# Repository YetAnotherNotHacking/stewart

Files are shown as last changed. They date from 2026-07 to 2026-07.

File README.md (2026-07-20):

<p align="center">
  Project Banner
</p>

<h1 align="center">Stewart Platform Controller</h1>

<p align="center">
  ESP32 • PCA9685 • 6 DoF
</p>

<p align="center">
  A simple, open implementation of a Stewart's platform with kinematics for all 6 DoF.
</p>

# About
This is a simple implementation of a Stewart's platform, something commonly used in settings like simulators or other applications of high strength high dof platforms. This uses an ESP32 and PCA9685 Servo Controller driving MG996r servos to allow for high quality control of the platform.

This reposity also includes a robust desktop control app, currently featuring jog movement and jump to position control for the platform using the ESP's wireless networking. It's planned for later integration for heavier automation (possibly Lua based) to make it easier to automate the platform.

## Resources:
Things to help you around this project

### Assembly
An assembly guide for how to build the project is here: [link](https://docs.google.com/presentation/d/1fX6R6pKFSlhVpZevY7VcBayyEp1o772PA0JAKRDqIYo/edit?usp=sharing)

### Wiring
An image showing the wiring nessecary for the project is below.:
stewartwiring

### Programming
See the `code/` folder of this repo!

The desktop code can be run be downloading all of the python files and running main.py. You may need to create an `__init__.py`. Once I have the hardware and confirm it's functionality, I will ship the app more properly as a cross compliled bundled application. For now, however, you are going to need to download and run all scripts.

The ESP32's code can be flashed like any other code. See more information at the end of the assembly guide.

### Bill of Materials:
You can see the bill of materials [here]([url](https://docs.google.com/spreadsheets/d/1tSShUhzgmsK12tPjXI03KWSomIxZK9p5Zw8UYwgLAco/edit?usp=sharing)). I am purchasing a 12v supply to fix another project, the buck is cheaper than a dedicated high amperage 5v supply. You can achieve the same thing with a 5v supply, with atleast 6 amps. The HackClub grant will not be used to pay for the power supply. This also assumes you have assorted m3 screws lying around, if you do not, add another 9.99 for [these]([url](https://www.amazon.com/Fgruh-750PCS-Assortment-Washers-Assorted/dp/B0FGV5FCBN)) on Amazon.

| Component | Qty | Unit Price | Total | Link |
|---|----:|---:|---:|---|
| Buck Converter (24V/12V → 5V) | 1 | $9.99 | $9.99 | https://www.amazon.com/HOMELYLIFE-Efficiency-Protection-Automotive-Surveillance/dp/B01M03288J |
| ESP32 | 1 | $9.99 | $9.99 | https://www.amazon.com/Development-integrates-Bluetooth-Connection-Programming/dp/B0FGHX4JZ7?s=electronics |
| Servo Controller (PCA9685) | 1 | $8.99 | $8.99 | https://www.amazon.com/EC-Buying-16-Channel-Interface-Expansion/dp/B0GD7BMXHH?s=electronics |
| Pushrods | 1 | $9.98 | $9.98 | https://www.amazon.com/Adjustable-Pushrod-Connector-Airplane-Aircraft/dp/B086C4Q5RS |
| MG996R Servos (6-Pack) | 1 | $21.39 | $21.39 | https://www.amazon.com/KEAcvise-Packs-mg996r-servo-Motor/dp/B0FGP9ZPJN |
| 12V Power Supply | 1 | $14.87 | $14.87 | https://www.ebay.com/itm/177618885952?var=477234645275 |
| **Total** | **6** |  | **$95.21** | |

### Adaptation:
Currently, this platform is more of a kinematics demo then something that solves any real problem. The step files and fusion export for the main assembly are included in the `cad/` folder to allow you to modify this for whatever needs you have. Feel free to use this, its open source and I put no requirements on it.

### Support:
If you ever need any support, feel free to create an issue on this repository and I will try to get back to you as fast as I can!

## Render:
0b346e73-0dd3-4ae0-838e-4d3ce46c3656

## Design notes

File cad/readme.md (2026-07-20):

# Cad
This is all of the cad for the project.
Main fusion export, and stl/step exports of all files are here.

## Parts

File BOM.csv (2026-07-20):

item | count | cost per | cost total | link
Buck Converter (24/12v to 5v) | 1 | 9.99 | 9.99 | https://www.amazon.com/HOMELYLIFE-Efficiency-Protection-Automotive-Surveillance/dp/B01M03288J
ESP32 | 1 | 9.99 | 9.99 | https://www.amazon.com/Development-integrates-Bluetooth-Connection-Programming/dp/B0FGHX4JZ7?s=electronics
Servo Controller | 1 | 8.99 | 8.99 | https://www.amazon.com/EC-Buying-16-Channel-Interface-Expansion/dp/B0GD7BMXHH?s=electronics
Pushrods | 1 | 9.98 | 9.98 | https://www.amazon.com/Adjustable-Pushrod-Connector-Airplane-Aircraft/dp/B086C4Q5RS
Servos MG996r | 1 | 21.39 | 21.39 | https://www.amazon.com/KEAcvise-Packs-mg996r-servo-Motor/dp/B0FGP9ZPJN
12 Volt power supply | 1 | 14.87 | 14.87 | https://www.ebay.com/itm/177618885952?var=477234645275

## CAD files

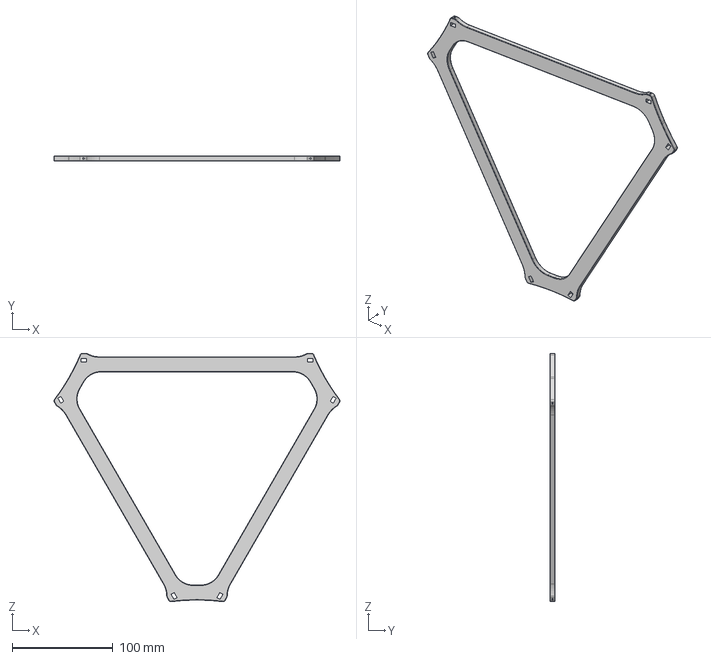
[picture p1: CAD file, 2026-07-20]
cad/plate.step
284.1 x 5.00 x 246.7 mm

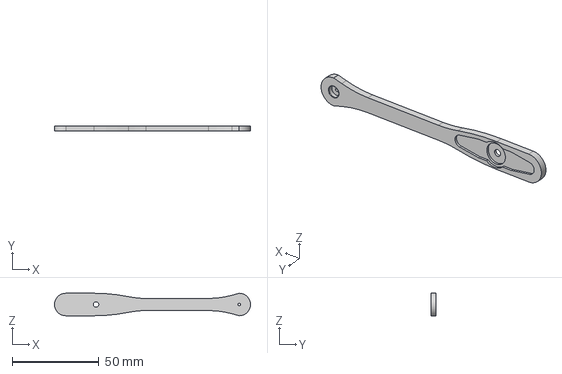
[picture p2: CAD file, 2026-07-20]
cad/control-arm.step
113.0 x 3.00 x 13.0 mm

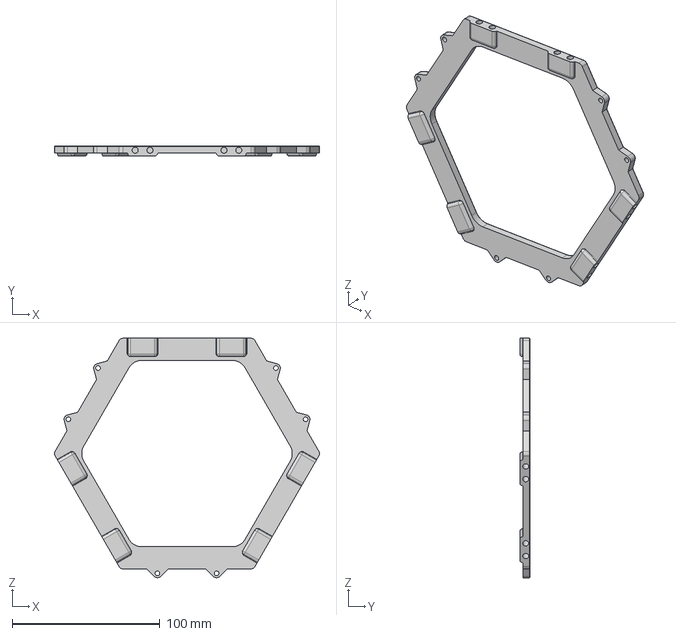
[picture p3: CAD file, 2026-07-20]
cad/top_plate.step
179.1 x 7.00 x 161.9 mm

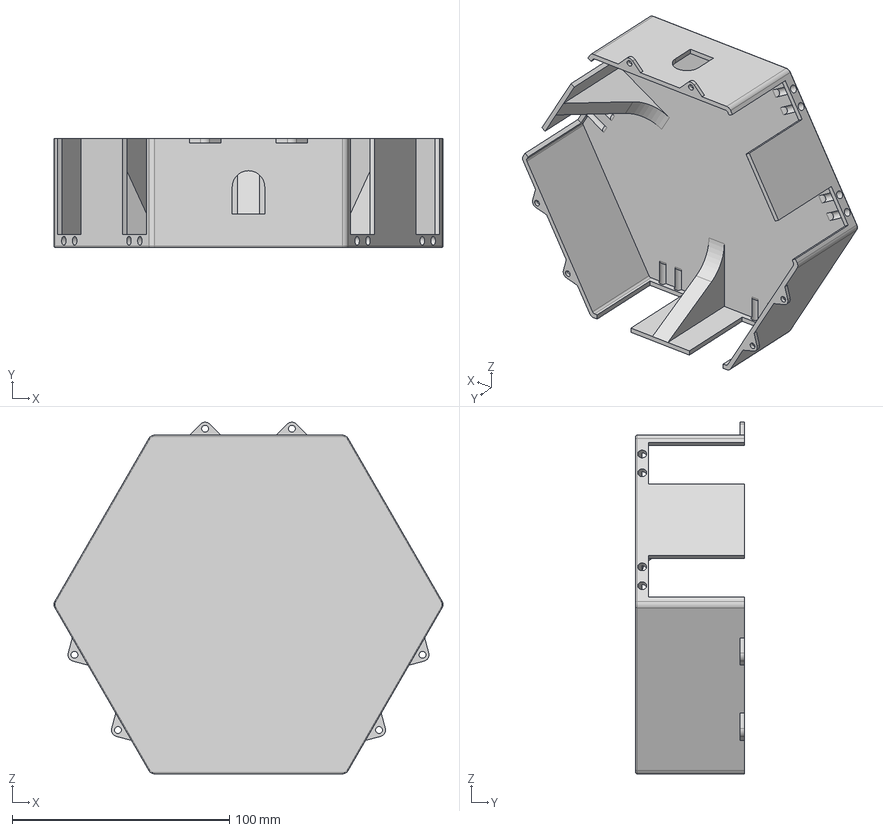
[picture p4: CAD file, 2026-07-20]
cad/base.step
179.1 x 50.0 x 161.9 mm

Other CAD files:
cad/base.stl
cad/control-arm.stl
cad/plate.stl
cad/top_plate.stl

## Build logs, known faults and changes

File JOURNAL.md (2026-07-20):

# July 4: Basic concept understanding, and working on the cad.
I have seen several other implementations of Stewart's platforms, however, all of them seemed to not nesecarily be super robust or able to take any decent payload. I want to make something that is able to have a generic payload adapter (similar to my previous gimbal project). I will look at another design for a base and try to work out how I can best increase the robustness and usability.

{7708621C-4849-4F1F-8B9E-15CF98B89B5D}

Above is the image that I am taking inspiration from. The design that they implemented is very simple, but you are able to see how everything works so I am going to use it as a base for my project.

I also had the recommendation from a friend to use mg996r servos for anything where any amount of load is being moved. I also concidered other servos, but looking around, the price to performance of the servos that he recommended are just best. They are also semi-frequently sold in packs of 6

Servo sourcing plan (cheap, good reviews, and 6 pack)

https://www.amazon.com/KEAcvise-Packs-mg996r-servo-Motor/dp/B0FGP9ZPJN

I am now going to figure out how closely I can logically package the servos into the base. The goal is a more compact base for easy adaptation in the future.

{B584B507-7369-4E37-B5E9-1328EBD415F6}

Above is what I came up with. It should be noted that the servos are sticking out, this is worst case clearance here to ensure they will fit well. There is also a plan to later integrate a 9 dof imu into the top of the case for later control improvements. (space is being left in the container so they will fit internally, to make later modification easier)

{6741CD3E-74F1-46A1-B29D-13A477A4EEA9}

This is what it looks like stood up. I notice that the 3 little walls (which will be bearing a decent amount of load) are really thin, and it is making me nervous, so I will ensure there are more layers for that to be a little more rigid in the future.

{BA7941BE-7033-4282-A654-466BBA05E55F}

I added the bottom screw holes (above). They look a bit weird, but I believe that this will be sufficient. If not, I have a rediculous amount of petg and can just reprint the part until its good enough. The plan will be to have the second (top) screw couples on the top element/top case. This is mainly to be easier to print without fail. I need to first make a way for the top of this to attach however.

{ADCCC9FD-2649-416B-894D-74BAC281DD39}

I added mounting holes for the top onto the walls that have less load on them to ballance it out. I also added a passthrough with some slight printing optimizations to the side to allow the power and possibly a control cable to be run through the side of the model.

{3E43B1B1-DBBC-4251-BCD3-43D21B207348}

Like I said, I was nervous about the thickness of these little walls so I have added these wedge things in order to improve the rigidity. I will have to account for them in the design of the top of this, as they are going right up to the edge of the wall. Anyway, I will now put everything together in the main assembly how it is to see how the packaging is looking.

{264E91C8-03C2-4743-A8B0-B292043C7E27}

I think it looks decent, I will continue with designing the top. I also see that with how I want to mount the servos, that they are going to require free space at the top of the model for their cables, this is unfortunate. I should also note that I am planning to use the left over m3 screws that I have from the Potatomatic project to assemble this in order to save costs.

{C7A08C58-994B-41CB-BDE0-317925B3F584}

Here is a rough concept of the top plate.

{55CF6593-B2A6-4264-8C56-0BE5EBFA97F7}

And here it is in the main assembly.

{2EB23810-CFFF-498B-9FF3-BDC86DFFC4B5}

Looking at where the servo attaches, it seems it will be nessecary for me to drop down the plate a little more for it to be thick enough on the bottom. I will also need to raise it roughly a millimeter on the top for more material there as well. It sucks that there is no way to print this that makes it so that the screw isnt going to be splitting the layers apart.

{193AC73F-C306-4EBB-A3E5-E983F9CDB948}

I have now polished the part.

{ACE63CB6-6EF3-4794-8CF9-CCE3B20B8174}

The screw holes for the servos are now properly in place and have sufficient thickness in the places where it's needed.

{DC22E7E0-B3A2-44E5-8347-32755850A53D}

This is the overall look now. I will next move onto the part of designing the control arms, but I first want to do a little bit of research to figure out how the length/other factors changes the behaviour.

https://raw.org/research/inverse-kinematics-of-a-stewart-platform/

I found this awesome website, with a super awesome article detailing the inverse kinematics, not only this, it allowed me to easily tweak the settings of the control arms and driving rod lengths. This gave valuable insight, as I now understand how the length effects it. I spent about 10 minutes looking a little bit into their code (which I understood none of :sob:) as well as playing with the length of the control arms.  From looking at it. the only effect that they really have is the range of motion that your platform has. For example, short control arms means you are only able to move your platform a little bit, but the lack of precision of the servos is accounted for a little bit better, and with longer ones, any error of the servos is amplified but you get decently larger range of motion. I also noticed if they are too long, they are able to collide with eachother. So next, I am going to find step files for the servo horns, and model a control arm that maximizes the achievable positions of the system.

{CC1C07BD-DBCB-4EA6-AB8A-6E77BAE61B1C}

Hmmmmm... those are going to collide at this size....
Luckily I made everything intent driven, so it will simply be changing a few numbers to change everything. Still sucks though.

{1E59FDD9-F150-4E86-BC50-04DC1E2669FB}

Fusion is testing my pacience. It broke the entire model for the base, I spent a bit fixing that. Some of the geometry sketches for the mounting holes were constrained wrongly when they were copied between the sketches, and a lot of them just decided they want to fail to compute. Then, after fixing all of the base, I tried updating the model just to see the damage, and was greeted with this wonderful piece of modern artwork (slop) that I will now have to spend my time fixing. Delightful!

{CC3863F8-A4AC-4C55-9D65-8D3235942493}

I will first fix this top plate, then reconstrain everything again. For me this feels less overwhelming then fixing a ton of small errors.

{464E0E61-C5F8-4216-B478-98CCD330A679}

Intent driven for the win :100: I love intent driven :heart:

The top was much easier to fix since I did everything properly. It was changing about 4 numbers between 2 sketches and everything was all good. I will now re insert and joint all of the servos together.

I also verified that the servos have the required range of motion, they seem to be 360 which is not standard for these servos to my understanding.

{35CF77CF-9B23-4C36-8AD6-604776D82AB0}

I now have all of the things put on there.

{0F38C60F-6E5E-4631-A7CB-6289051E86CA}

Here is the hole that the servo horn is going to get put on.

{7766989E-C96C-4622-A41C-EEDB0266B852}

I realized I forgot the way to screw it in, this is what I came up with. The m3 screw that is included will be too short, so I am going to replace it with one of my own, longer ones. I may also improve this geometry, but my printer is probably too crap for it to matter anyway.

{7359E234-FEF2-4035-8B6E-4F17F7F43342}

I made the arm a little thinner, it was really thick, and it will be in petg so I know the strength is not going to be an issue.

{42FDEA49-88B1-4488-A795-8FD30214A6F2}

I have continued to optimize this for the control rod attachment, I made sure that the fixtures will attach as best as possible. I am still a little unsure of how it will all end up factoring together, so I will try and make the push rods next just to see what they are going to look like roughly.

{0284CCE8-381B-44F2-9D7C-2662C3E2D7CF}

Man...... these pushrods are really thin aren't they.....
Im sure it wont be a problem

https://www.amazon.com/HobbyPark-Adjustable-Connector-Pushrods-Replacement/dp/B08CBSWMR5/141-2591928-2634929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

Above are the pushrods that I am intending to get btw. I also had to learn how to use the sweep tool to make them in fusion :sob:

{E34BBB38-DA87-4670-9158-C333024C7C63}

I may end up shortening the control rods in real life if they aren't rigid enough. They look like they will fail fast honestly. I also worry that once they are bent, that they aren't going to be easy to unbend and get working again.

Sorry for big dev log today. It is currently the next day actually, so this is technically multiple days of work.

I also made a bom, this was a few days ago when I was still planning the rough idea of the project out, but it is still unlogged work.

https://docs.google.com/document/d/1bmJ8n-eDoXSdFWSxfQN4pvn6DaG_fgnzeeZT4vmXuGE/edit?usp=sharing

** Total time spent: 5.9 hours **

# July 5: Working on the top payload, and kinematics/code
I speant the first 40 minutes today working on the top platform that the plate will be attached to. I still dont know for sure what I am going to do for the plate, it will have to be something transparent to make use cases like bouncing a ping pong ball easier.

{D2C29C5F-D418-43F5-B01C-BD269D2E2E26}

Above is the image of what that looks like in the overall design. I cant decide if I am going to bend the push rods like shown, or if I am going to take advantage of the link things that come in the kit of them. The kit isnt super clear about their size so I dont know how to cad for them without having that. I have a place to either bend the wire or put a bolt, depending on what I end up doing.

Youtube of cad, stopped trying lapse because it NEVER works. Sorry for 1x speed, and weird aspect ratio (peak framework).
https://www.youtube.com/watch?v=UD7uxmYwpVk

I will now look into how I can implement the kinematics engine into python.

For working on the kinematics, I need to first get some of the main parameters for the control, those are: horn length, rod length, base radius and base raduis outer, platform radius, platform radius outer, shaft distance, anchor distance. (disclosure: I am getting help from Gemini to understand the kinematics, as well as refferencing the stewart.js from the web demo I talked about yesterday. I don't understand a majority of the math so I am seeking LLM assistance, everything else I will be writing myself.)

Here are the values I have measured from my model (note: all in mm)

```python
horn_length = 82.50
rod_length = 169.00
base_radius = 97.342
base_radius_outer = 90.00
platform_radius = 81.293
platform_radius_outer = 123.198
shaft_distance = 30.00
anchor_distance = 112.50
```

Horn length: 

{3A344BA8-43A7-4DE4-A1C0-9EBD12153CDD}

Rod length:

{7ADF7757-6D76-44C3-9E2A-94BBC2EA63F2}

Base Radius:

{16644CE8-8193-4C16-9567-7A8AE65D8448}

{168CA614-B971-422A-B4B4-20F02DB826A6}

Base Radius (outer):

{52B913E2-7397-4D8C-B3CC-4CA2CCBF47E9}

Platform Radius:

{A6326FF2-A38A-445D-87B1-B7B76F02757F}

Platform Radius (outer):

{00A32B14-F5F0-42A4-81A5-427C9D99E484}

Shaft Distance:

{BF8E1D49-5830-47E3-A02E-939B34D53DE6}

Anchor Distance:

{696FCF2E-CB64-4703-B590-D0A17781D279}

Now that I have these measurements, I am going to boot back into Linux where my development environment is, and work on the rest of the programming. I want to make a TKinter control GUI, and basic easy to control kinematics. I plan to also look into how difficult a 3d preview of the movements would be. I also need to write the firmware for the esp32 that it will be controlling. The idea is to have the code run mainly on the laptop, and use the lan to connect to the esp32 and issue the servo angles. All kinematics will be done in the desktop companion app for simplicity.

I spent about 2 more hours working on the code for the project, this simple tkinter gui was super obnoxious to make. I just need to add jump to position, position validity verification, connection logic and piping the position to the kinematics so the commands can be sent and this project will largely be completed. Overall, I think that this is not the most complicated part of the gui and that a lot more time is going to need to be spent in order to complete this. Namely, the connection is something that is going to take a while. I most likely will want to do something websocket based running on the esp32, and some of light feedback in it for better control. I am not sure yet. I also want to add a 3d visualizer to the gui, similar to the one website that I found the stewart.js library from. Overall, with what was done today I know that there is still a lot more to come. In the end, this is a code heavy project rather than hardware heavy (hence me doing t3).



Note: yes, it's open in antigravity, but thats bc its the only ide I have configured with everything on this machine (other than FRC VSCode which is missing hackatime). The hackatime project is stewartcontroller, I tried to share it, but it says "anyone with the link can view it" but I litteraly cant find a public link anywhere. The only link I see has /my/ which I know won't work on another machine, if it did, so many duplicates would have to exist. I will assume it being public is enough for whoever is reviewing the project. Lmk if there is anything else that I need to do. I did also get some help with small syntax errors from ChatGPT and other missuses of tkinter, bc honestly this is my first time in a while not just fully vibe coding the interface, I have forgotten most of even the basic stuff unfortunately. I used to be good at this :sob:

** Total Time Spent: 3.5 hours **

# July 19: Finishing code, finalizing for ship
After finishing getting distracted by the FTC premier event and working on a new drivebase for next year, I finally have gone back to this project to get it finished and out of the way. I also need the 12v supply this project will fund over other things, so I am trying to get this shipped asap. I know Forge is against AI firmware, but I dont really know cpp so I had to get some help from gemini. I used it to assist with basic usage of the apis I needed to host a wireless network and parse json in order to control this project effectively.

I ended up finishing it up, and it looks something like this:



Litteraly just accepting a json object of the positions and sending the pwm signal to each of the servos in order to set their position.

I also had some assistance from gemini in order to create a visualization of the platform:



I have kept it so that the code is less than 30% written by ai, though of the 70% of my code about 50% of it was written with assistance (asking how to use apis in context, but implemnting myself) (all of this is just as a disclosure)

I will now boot back into windows and begin work on assembly, wiring, and other finalization to meet the requirements. I will also copy the code from the other repository that I made accidentally to here.

{FB7F5493-3F80-4C67-B9E0-88EF0DA67D7C}

I have made the bom.csv (above). it should be noted that the 12v and buck are nessecary rather than just a 5v, as the power supply is needed to save another Forge project I can't complete since the power supply unfortunately was fried. (This is to fix Potatomatic)

I have also exported all of the cad in the requested format as well as stl for easier printing of the project. Its all in the `cad/` folder of the repo. I will next complete the assembly guides and wiring diagrams.

Here is the finished assmebly guide and wiring diagram combo:

https://docs.google.com/presentation/d/1fX6R6pKFSlhVpZevY7VcBayyEp1o772PA0JAKRDqIYo/edit?usp=sharing

Finally, I made an image in sketchpad for the repo banner and forge banner.

{38EFED0E-58FD-4C1D-82DD-88AE67AA784D}

I then put together the readme file, finalized everything to meet the forge shipping requirements, all of this took a little over 30 minutes however I was waiting for a render for part of that time that I will not count. I ended up scrapping that render and using the one from the assembly guide anyway.

{5F63E4D0-7F8A-474A-ABB6-F0F511B82756}

I will now update this journal one final time and submit the project for review!

Hackatime: 


** Total time spent: 2.6 hours **

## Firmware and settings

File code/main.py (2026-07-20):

from tkinter import constants
from scipy.spatial.transform import Rotation as R
from kinematics import StewartKinematicSolver
import tkinter as tk
from tkinter import ttk
import numpy as np
from render import PlatformRenderer
import urllib.request
import json
import threading

class ControlApp(tk.Tk):
    def __init__(self):
        super().__init__()

        self.title("Stewart platform control")
        self.geometry("1400x1200")
        self.minsize(1400, 1200)

        self.grid_rowconfigure(0, weight=1)
        self.grid_columnconfigure(0, weight=1)

        # movement values
        self.motion = {
            "x": 0,
            "y": 0,
            "z": 0,
            "tilt_x": 0,
            "tilt_y": 0,
            "spin": 0
        }

        # connection state
        self.isconnect = tk.BooleanVar(value=False)
        self.deviceip = tk.StringVar(value="192.168.4.1")
        self.deviceport = tk.IntVar(value=80)

        self.movescale = tk.IntVar(value=25)
        self.solver = StewartKinematicSolver.create_hexagonal()

        self.saved_positions = {'c1': None, 'c2': None}
        self.animating = False

        self.create_widgets()
        
        # update display to initial position
        self.move(0, 0, 0, 0, 0, 0)

    # Update handlers
    def on_scale_change(self):
        print(f"Move scale updated to {self.movescale.get()}mm")

    def move_absolute(self, x, y, z, tilt_x, tilt_y, spin):
        revert_state = self.motion.copy()
        self.motion["x"] = x
        self.motion["y"] = y
        self.motion["z"] = z
        self.motion["tilt_x"] = tilt_x
        self.motion["tilt_y"] = tilt_y
        self.motion["spin"] = spin
        return self._apply_motion(revert_state)

    def _apply_motion(self, revert_state=None):
        target_translation = [self.motion["x"], self.motion["y"], self.motion["z"]]
        target_rotation = R.from_euler('xyz', [self.motion["tilt_x"], self.motion["tilt_y"], self.motion["spin"]], degrees=True)
        
        angles = self.solver.solve(target_translation, target_rotation)
        
        if angles is not None:
            angles_deg = np.degrees(angles)
            for i in range(6):
                self.servo_labels[i].config(text=f"Servo {i+1}: {angles_deg[i]:.2f}°")
            self.posstatus.config(text=f"pos is {self.motion['x']:.1f}, {self.motion['y']:.1f}, {self.motion['z']:.1f} at {self.motion['tilt_x']:.1f}, {self.motion['tilt_y']:.1f}, {self.motion['spin']:.1f}")
            
            if hasattr(self, 'renderer'):
                self.renderer.render(target_translation, target_rotation)
                
            self.send_angles(angles_deg)
            return True
        else:
            self.posstatus.config(text="Out of mechanical bounds!")
            if revert_state is not None:
                self.motion = revert_state.copy()
            return False

    def move(self, x=0, y=0, z=0, tilt_x=0, tilt_y=0, spin=0):
        scale = self.movescale.get()
        revert_state = self.motion.copy()
        
        self.motion["x"] += x * scale
        self.motion["y"] += y * scale
        self.motion["z"] += z * scale
        self.motion["tilt_x"] += tilt_x * scale
        self.motion["tilt_y"] += tilt_y * scale
        self.motion["spin"] += spin * scale

        self._apply_motion(revert_state)

    def save_pos(self, slot):
        self.saved_positions[slot] = self.motion.copy()
        
    def jump_saved(self, slot):
        if self.saved_positions[slot]:
            target = self.saved_positions[slot]
            self.jump_to(target['x'], target['y'], target['z'], target['tilt_x'], target['tilt_y'], target['spin'])

    def jump_to(self, x, y, z, tx, ty, spin):
        if self.animating: return
        self.animating = True
        
        start = self.motion.copy()
        target = {'x': x, 'y': y, 'z': z, 'tilt_x': tx, 'tilt_y': ty, 'spin': spin}
        
        steps = 20
        delay_ms = 20
        
        def animate_step(step):
            if step > steps:
                self.animating = False
                return
                
            t = step / steps
            smooth_t = t * t * (3 - 2 * t)
            
            curr_x = start['x'] + (target['x'] - start['x']) * smooth_t
            curr_y = start['y'] + (target['y'] - start['y']) * smooth_t
            curr_z = start['z'] + (target['z'] - start['z']) * smooth_t
            curr_tx = start['tilt_x'] + (target['tilt_x'] - start['tilt_x']) * smooth_t
            curr_ty = start['tilt_y'] + (target['tilt_y'] - start['tilt_y']) * smooth_t
            curr_spin = start['spin'] + (target['spin'] - start['spin']) * smooth_t
            
            success = self.move_absolute(curr_x, curr_y, curr_z, curr_tx, curr_ty, curr_spin)
            if not success:
                self.animating = False
                return
                
            self.after(delay_ms, lambda: animate_step(step + 1))
            
        animate_step(1)

    def create_widgets(self):
        main = ttk.Frame(self, padding=5)
        main.grid(row=0, column=0, sticky="nsew")
        main.grid_rowconfigure(0, weight=0) # top bar
        main.grid_rowconfigure(1, weight=1) # body
        main.grid_columnconfigure(0, weight=0)
        main.grid_columnconfigure(1, weight=1)

        # --- Top Bar ---
        topbar = ttk.Frame(main)
        topbar.grid(row=0, column=0, columnspan=2, sticky="ew", pady=(0, 10))
        topbar.grid_columnconfigure(1, weight=1) # Allow position log to expand
        
        # Network Connection
        connframe = ttk.LabelFrame(topbar, text="Network Connection", padding=5)
        connframe.grid(row=0, column=0, sticky="w", padx=5)
        
        ttk.Label(connframe, text="IP:").grid(row=0, column=0, padx=2)
        ttk.Entry(connframe, textvariable=self.deviceip, width=15).grid(row=0, column=1, padx=2)
        ttk.Label(connframe, text="Port:").grid(row=0, column=2, padx=2)
        ttk.Entry(connframe, textvariable=self.deviceport, width=5).grid(row=0, column=3, padx=2)
        self.connect_btn = ttk.Button(connframe, text="Connect", command=self.toggle_connect)
        self.connect_btn.grid(row=0, column=4, padx=5)
        
        # Position Log
        statusframe = ttk.LabelFrame(topbar, text="Status", padding=5)
        statusframe.grid(row=0, column=1, sticky="ew", padx=5)
        self.posstatus = ttk.Label(statusframe, text='pos is 0.0, 0.0, 0.0 at 0.0, 0.0, 0.0')
        self.posstatus.pack(fill="both", expand=True)

        # Jumps
        jumpsframe = ttk.LabelFrame(topbar, text="Jumps", padding=5)
        jumpsframe.grid(row=0, column=2, sticky="e", padx=5)
        
        ttk.Button(jumpsframe, text="Home", command=lambda: self.jump_to(0,0,0,0,0,0)).grid(row=0, column=0, columnspan=2, pady=2, sticky="ew")
        
        ttk.Button(jumpsframe, text="Save C1", command=lambda: self.save_pos('c1')).grid(row=1, column=0, padx=2)
        ttk.Button(jumpsframe, text="Jump C1", command=lambda: self.jump_saved('c1')).grid(row=1, column=1, padx=2)
        
        ttk.Button(jumpsframe, text="Save C2", command=lambda: self.save_pos('c2')).grid(row=2, column=0, padx=2)
        ttk.Button(jumpsframe, text="Jump C2", command=lambda: self.jump_saved('c2')).grid(row=2, column=1, padx=2)

        # --- Body ---
        jogframe = ttk.LabelFrame(main, text="Jog", padding=10)
        jogframe.grid(row=1, column=0, padx=10, pady=10, sticky="nw")

        planeframe = ttk.LabelFrame(jogframe, text="2D Movement", padding=10)
        planeframe.grid(row=0, column=0, padx=10, pady=10, sticky="w")
        
        # 2d plane (primary?) movement
        forwardbutton = tk.Button(planeframe,
            height=2,
            width=4,
            text = "fw",
            command=lambda: self.move(y=1))
        backbutton = tk.Button(planeframe,
            height=2,
            width=4,
            text="bk",
            command=lambda: self.move(y=-1))

        leftbutton = tk.Button(planeframe,
            height=2,
            width=4,
            text="lf",
            command=lambda: self.move(x=-1))
        rightbutton = tk.Button(planeframe,
            height=2,
            width=4,
            text="rt",
            command=lambda: self.move(x=1))

        forwardbutton.grid(row=0, column=1)
        leftbutton.grid(row=1, column=0)
        rightbutton.grid(row=1, column=2)
        backbutton.grid(row=2, column=1)

        # height adjustment
        heightframe = ttk.LabelFrame(jogframe, text="Height", padding=10)
        heightframe.grid(row=0, column=1, padx=10, pady=10, sticky="e")
        upbutton = tk.Button(heightframe,
            height=2,
            width=4,
            text="up",
            command=lambda: self.move(z=1))
        downbutton = tk.Button(heightframe,
            height=2,
            width=4,
            text="dn",
            command=lambda: self.move(z=-1))
        upbutton.grid(row=0, column=0)
        downbutton.grid(row=2, column=0)

        # tilt adjustments
        tiltframe = ttk.LabelFrame(jogframe, text="Tilt Control", padding=10)
        tiltframe.grid(row=1, column=0, padx=10, pady=10, sticky="w")
        tiltforward = tk.Button(tiltframe,
            height=2,
            width=4,
            text="fw",
            command=lambda: self.move(tilt_x=1))
        tiltback = tk.Button(tiltframe,
            height=2,
            width=4,
            text="bk",
            command=lambda: self.move(tilt_x=-1))

        tiltleft = tk.Button(tiltframe,
            height=2,
            width=4,
            text="lf",
            command=lambda: self.move(tilt_y=-1))
        tiltright = tk.Button(tiltframe,
            height=2,
            width=4,
            text="rt",
            command=lambda: self.move(tilt_y=1))

        spinleft = tk.Button(tiltframe,
            height=2,
            width=4,
            text="s-",
            command=lambda: self.move(spin=-1))
        spinright = tk.Button(tiltframe,
            height=2,
            width=4,
            text="s+",
            command=lambda: self.move(spin=1))

        tiltforward.grid(row=3, column=0)
        tiltback.grid(row=4, column=0)
        tiltleft.grid(row=3, column=1)
        tiltright.grid(row=4, column=1)
        spinleft.grid(row=3, column=2)
        spinright.grid(row=4, column=2)

        scaleframe = ttk.LabelFrame(jogframe, text="Scale", padding=10)
        scaleframe.grid(row=1, column=1, padx=10, pady=10, sticky="se")

        op1 = ttk.Radiobutton(scaleframe, 
            text="1mm", 
            variable=self.movescale, 
            value=1, 
            command=self.on_scale_change)
        
        op2 = ttk.Radiobutton(scaleframe, 
            text="10mm", 
            variable=self.movescale, 
            value=10,
            command=self.on_scale_change)
        
        op3 = ttk.Radiobutton(scaleframe, 
            text="15mm", 
            variable=self.movescale, 
            value=15, 
            command=self.on_scale_change)
    
        op4 = ttk.Radiobutton(scaleframe, 
            text="20mm", 
            variable=self.movescale, 
            value=20, 
            command=self.on_scale_change)

        op1.grid(row=0, column=0, pady=2)
        op2.grid(row=1, column=0, pady=2)
        op3.grid(row=2, column=0, pady=2)
        op4.grid(row=3, column=0, pady=2)

        servosframe = ttk.LabelFrame(main, text="Servo Angles", padding=10)
        servosframe.grid(row=2, column=0, padx=10, pady=10, sticky="nw")
        
        self.servo_labels = []
        for i in range(6):
            lbl = ttk.Label(servosframe, text=f"Servo {i+1}: 0.00°")
            lbl.grid(row=i//2, column=i%2, padx=10, pady=2, sticky="w")
            self.servo_labels.append(lbl)

        visframe = ttk.LabelFrame(main, text="Visualization", padding=10)
        visframe.grid(row=1, column=1, rowspan=2, padx=10, pady=10, sticky="nsew")
        
        self.renderer = PlatformRenderer(visframe, self.solver)
        self.renderer.pack(expand=True, fill="both")

    def toggle_connect(self):
        if not self.isconnect.get():
            self.isconnect.set(True)
            self.connect_btn.config(text="Disconnect")
            self.move() # Trigger a send of current angles immediately
        else:
            self.isconnect.set(False)
            self.connect_btn.config(text="Connect")

    def send_angles(self, angles_deg):
        if not self.isconnect.get():
            return
            
        # Shift -90 to +90 degrees into 0 to 180 degrees for standard servos
        payload = {
            "servos": [{"id": i, "angle": int(angles_deg[i] + 90)} for i in range(6)]
        }
        
        url = f"http://{self.deviceip.get()}:{self.deviceport.get()}/set"
        
        def _send():
            try:
                req = urllib.request.Request(url, method="POST")
                req.add_header('Content-Type', 'text/plain') # ESP32 WebServer parses 'plain' nicely
                data = json.dumps(payload).encode('utf-8')
                urllib.request.urlopen(req, data=data, timeout=0.5)
            except Exception as e:
                print(f"Failed to send to ESP: {e}")
                
        # Send in a background thread so the GUI doesn't freeze on network timeouts
        threading.Thread(target=_send, daemon=True).start()

    def run(self):
        self.mainloop()

if __name__ == "__main__":
    app = ControlApp()
    app.run()

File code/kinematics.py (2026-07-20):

# Kinematics utilities for stewart's platform movement.
# NOTICE: This is LLM code. Generated with Gemini 3.1 Pro.

import math
import numpy as np
from scipy.spatial.transform import Rotation as R
from typing import List, Tuple, Union, Optional

class StewartKinematicSolver:
    """
    Inverse Kinematics Solver for a Stewart Platform.
    All distance units are assumed to be in millimeters (mm) and angles in radians.
    """

    def __init__(
        self,
        base_joints: List[np.ndarray],
        platform_joints: List[np.ndarray],
        motor_rotations: List[float],
        rod_length: float,
        horn_length: float,
        servo_range: Tuple[float, float] = (-math.pi / 2, math.pi / 2),
        absolute_height: bool = False
    ):
        """
        Initialize the Stewart Platform kinematic solver.
        
        :param base_joints: List of 6 3D coordinates [x, y, z] for base mount points (mm).
        :param platform_joints: List of 6 3D coordinates [x, y, z] for platform mount points (mm).
        :param motor_rotations: List of 6 angles (radians) representing the pan angle of each motor on the base.
        :param rod_length: Length of the connecting rods (mm).
        :param horn_length: Length of the servo horns (mm).
        :param servo_range: Tuple of (min_angle, max_angle) in radians for the servos.
        :param absolute_height: If False, automatically calculates the resting Z-height (T0).
        """
        assert len(base_joints) == 6, "Must provide exactly 6 base joints"
        assert len(platform_joints) == 6, "Must provide exactly 6 platform joints"
        assert len(motor_rotations) == 6, "Must provide exactly 6 motor rotations"

        self.B = np.array(base_joints, dtype=float)
        self.P = np.array(platform_joints, dtype=float)
        self.beta = np.array(motor_rotations, dtype=float)
        self.sin_beta = np.sin(self.beta)
        self.cos_beta = np.cos(self.beta)
        
        self.rod_length = rod_length
        self.horn_length = horn_length
        self.servo_range = servo_range

        # Calculate base offset (T0)
        if absolute_height:
            self.T0 = np.array([0.0, 0.0, 0.0])
        else:
            # Calculate resting z-height based on rod and horn lengths
            dx = self.P[0][0] - self.B[0][0]
            dy = self.P[0][1] - self.B[0][1]
            z_sq = (rod_length**2 + horn_length**2) - (dx**2 + dy**2)
            
            if z_sq < 0:
                raise ValueError("Platform geometry is physically impossible with these rod/horn lengths.")
                
            self.T0 = np.array([0.0, 0.0, math.sqrt(z_sq)])

    def solve(self, translation: Union[List[float], np.ndarray], rotation: R) -> Optional[np.ndarray]:
        """
        Calculates the required servo horn angles to achieve the requested translation and rotation.
        
        :param translation: [x, y, z] translation vector in mm.
        :param rotation: scipy.spatial.transform.Rotation object representing the platform's orientation.
        :return: A numpy array of 6 servo angles in radians, or None if the position is unreachable.
        """
        translation = np.array(translation, dtype=float)
        
        # Calculate rotated platform joints
        P_rotated = rotation.apply(self.P)
        
        # Calculate platform joint position in base frame (q)
        # q_i = T + R * P_i + T0
        q = translation + P_rotated + self.T0
        
        # Vector from Base joint to Platform joint (l)
        l = q - self.B
        
        angles = np.zeros(6)
        
        for i in range(6):
            lx, ly, lz = l[i]
            
            gk = lx**2 + ly**2 + lz**2 - self.rod_length**2 + self.horn_length**2
            ek = 2 * self.horn_length * lz
            fk = 2 * self.horn_length * (self.cos_beta[i] * lx + self.sin_beta[i] * ly)
            
            sq_sum = ek**2 + fk**2
            
            # Check if geometry allows a valid rod intersection
            val_under_sqrt = 1 - (gk**2 / sq_sum)
            if val_under_sqrt < 0:
                return None  # Unreachable position (rod is too short/long)
                
            sqrt1 = math.sqrt(val_under_sqrt)
            sqrt2 = math.sqrt(sq_sum)
            
            sin_alpha = (gk * ek) / sq_sum - (fk * sqrt1) / sqrt2
            cos_alpha = (gk * fk) / sq_sum + (ek * sqrt1) / sqrt2
            
            # Use atan2 for robust angle resolution instead of raw arcsin
            alpha = math.atan2(sin_alpha, cos_alpha)
            
            # Constrain to servo limits
            if not (self.servo_range[0] <= alpha <= self.servo_range[1]):
                return None  # Out of mechanical bounds
                
            angles[i] = alpha
            
        return angles

    def is_reachable(self, translation: Union[List[float], np.ndarray], rotation: R) -> bool:
        """
        Checks if a specific pose can be mechanically reached by the platform.
        """
        return self.solve(translation, rotation) is not None

    @classmethod
    def create_hexagonal(
        cls,
        base_radius: float = 97.342,
        base_radius_outer: float = 110.0,
        platform_radius: float = 81.293,
        platform_radius_outer: float = 123.198,
        rod_length: float = 169.00,
        horn_length: float = 82.50,
        horn_direction: int = 0,
        shaft_distance: float = 30.00,
        anchor_distance: float = 112.50,
        platform_turn: bool = True,
        servo_range: Tuple[float, float] = (-math.pi / 2, math.pi / 2)
    ):
        """
        Factory method to generate a Hexagonal Stewart Platform configuration.
        Matches `initHexagonal` behavior from the JS library.
        """
        def _get_hex_plate(r_i, r_o, rot):
            ret = []
            a_2 = (2 * r_i - r_o) / math.sqrt(3)
            for i in range(6):
                phi = (i - i % 2) / 3 * math.pi + rot
                ap = a_2 * (-1 if (i & 1) else 1)
                ret.append([
                    r_o * math.cos(phi) + ap * math.sin(phi),
                    r_o * math.sin(phi) - ap * math.cos(phi)
                ])
            return np.array(ret)

        base_ints = _get_hex_plate(base_radius, base_radius_outer, 0)
        plat_ints = _get_hex_plate(platform_radius, platform_radius_outer, math.pi if platform_turn else 0)

        base_points = []
        plat_points = []
        motor_angles = []

        for i in range(6):
            mid_k = i | 1
            base_c = base_ints[mid_k]
            base_n = base_ints[(mid_k + 1) % 6]
            plat_c = plat_ints[mid_k]
            plat_n = plat_ints[(mid_k + 1) % 6]

            base_d = base_n - base_c
            len_base_side = np.linalg.norm(base_d)
            base_d /= len_base_side

            pm = -1 if (i & 1) else 1

            base_mid = (base_c + base_n) / 2
            plat_mid = (plat_c + plat_n) / 2
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

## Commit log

2026-07-05 update with correction (I was typing on power saver ig)
2026-07-06 update for the top plate
2026-07-20 add kinematic solver for platform control
2026-07-20 Add initial README for the Cad project
2026-07-20 add step and stl of indivudiaul components
    [base.step, base.stl, control-arm.step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]
2026-07-20 add main assembly archive
2026-07-20 add work for assembly guide, wiring diagram, update time for those two things
2026-07-20 Revise bill of materials and add component details
    Updated the bill of materials with detailed pricing and links for components. Clarified power supply options and added a table for better organization.
